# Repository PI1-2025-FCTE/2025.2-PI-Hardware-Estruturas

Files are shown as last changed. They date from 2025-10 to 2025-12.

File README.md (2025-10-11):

# Veículo Autônomo para Depósito de Objetos
Este projeto está vinculado a disciplina de Projeto Integrador 1, da Universidade de Brasília, ministrada pelo Prof. Dr. Lui Txai Calvoso Habl. Tem por objetivo o desenvolvimento de um **veículo autônomo** capaz de seguir trajetórias predefinidas e depositar um objeto do tamanho, proporção e fragilidade de um ovo médio em uma caixa acolchoada ao término da trajetória, sendo operado por uma interface gráfica que retornará o tempo e a trajetória do veiculo. 

[Documentação Latex](https://www.overleaf.com/5331879129xcxkbjkxxrrc#4cba63)

[Esquemático do circuito](https://easyeda.com/editor#project_id=84deaf6a43b146378309fcd01e6a131c)
## Objetivos

- **Trajetórias e Navegação**:
  O carrinho deverá seguir **três diferentes trajetórias**:
  1. **Primeira Trajetória**: Indicação visual com fita isolante no piso.
  2. **Segunda Trajetória**: Indicação visual com fita isolante intermitente.
  3. **Terceira Trajetória**: Indicação de percurso baseada apenas em instruções dadas pelos professores (sem marcação visual).
  
- **Depósito do Objeto**: O carrinho deverá **transportar um objeto frágil (ovo médio)** e entregá-lo de forma segura em uma caixa acolchoada no final da trajetória.

## Etapas do Projeto

### 1. **Desenvolvimento Conceitual**
- Características gerais do carrinho e suas funcionalidades.
- Descrição detalhada do hardware e software envolvidos.
- Análise do consumo energético.

### 2. **Levantamento de Requisitos**
- Brainstorming
- Organização de Requisitos 
- Separação de requisitos por área de desenvolvimento
- Levantamento de Requisitos de baixo nível 

### 3. **Planejamento**
- Definição do cronograma de desenvolvimento.
- Estimativas de custos e orçamento.

### 4. **Prototipagem e Testes**
- Protótipos de hardware e simulação das trajetórias.
- Testes de desempenho (tempo e distância).
- Ajustes e validação de cada parte do sistema.

### 5. **Documentação**
- Desenvolvimento contínuo de artigo científico, documentando cada etapa do projeto.

### 6. **Entrega Final**
- Apresentação do projeto final, incluindo um vídeo de demonstração do funcionamento do carrinho.
- Relatório final com descrição detalhada dos resultados experimentais e análise do desempenho do carrinho.

---

## Tecnologias Utilizadas

- **Hardware**:
  - Sensores de movimento (IMU, giroscópio, etc.).
  - Atuadores (motores, rodas).
  - Microcontroladores e componentes eletrônicos.

- **Software**:
  - Interface gráfica para programação das trajetórias.
  - Banco de dados para registro e análise dos dados coletados.
  - Linguagens de programação: C++, Python, ou outras adequadas para controle de hardware.

- **Comunicação**:
  - Comunicação sem fio (Wi-Fi, Bluetooth, etc.).

## Contribuições

O desenvolvimento do projeto será realizado por uma equipe multidisciplinar, com a contribuição de **engenharias da FCTE** (Faculdade de Ciências e Tecnologia da Engenharia).

Cada membro da equipe será responsável por diferentes áreas, incluindo hardware, software, estrutura, e documentação do projeto.

## Licença

Este projeto está licenciado sob a [Licença MIT](https://opensource.org/licenses/MIT).

---

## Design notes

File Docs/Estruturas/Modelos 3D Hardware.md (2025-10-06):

# Em vez de modelar os componentes eletrônicos perfeitamente, modelar apenas como formas geométricas simplificadas.
## As dimensões estão na planilha: https://unbbr-my.sharepoint.com/:x:/g/personal/221007822_aluno_unb_br/EUa8brnz7TBNpTx4DXP05wEBW7xej8ZXPvB6gErNKME9qA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

- ESP:
https://grabcad.com/library?page=1&time=all_time&sort=recent&query=esp32%20wroom%2032
  - <s> Testado: https://grabcad.com/library/esp32-terminal-adapter-1
  - Compatível: Tem que separar a ESP da placa de dev na modelagem 3d, vem em stl ent tem muitos triângulos, talvez seja melhor procurar outro
  - Dimensões: </s>
  - [x] Modelado
  
- MOTOR:
https://grabcad.com/library/3-6v-dc-gearbox-electromotor-1
  - <s> Testado:
  - Compatível: Precisa converter de .ipt para .stl, provavelmente usando AutoDesk
  - Dimensões: </s>
  - [x] Modelado

- SENSOR VELOCIDADE: 
https://grabcad.com/library/lm393-motor-speed-measuring-sensor-module-1
  - <s> Testado: https://grabcad.com/library/lm393-motor-speed-measuring-sensor-module-1
  - Compatível:
  - Dimensões: 31,3mm X 14,2mm X 11,815mm </s>
  - [x] Modelado

- DISCO ENCODER: 
https://grabcad.com/library/encoder-disk-2
  - <s> Testado: https://grabcad.com/library/encoder-disk-2 
  - Compatível: Arquivo "encoder disk.STEP"
  - Dimensões: D: 25,756 mm / Espessura máx: 3,175 mm / Espessura mín: 2,54 mm </s>
  - [x] Modelado

- RODA TRASEIRA:
  - <s> Testado:
  - Compatível:
  - Dimensões: </s>
  - [x] Modelado

- ACELERÔMETRO: 
https://grabcad.com/library/mpu-9250-1
  - <s> Testado: https://grabcad.com/library/mpu-9250-1
  - Compatível: Arquivo "MPU-9250.stp"
  - Dimensões: 15 mm x 25 mm x 12,696 mm (Profundidade máxima devido ao tamanho dos pinos presentes no CAD) </s>
  - [x] Modelado
    
- RODA DIANTEIRA: 
https://grabcad.com/library?page=1&time=all_time&sort=recent&query=ball%20caster
  - <s> Testado:
  - Compatível:
  - Dimensões: </s>
  - [ ] Modelado
    
- PLACA DE DESENVOLVIMENTO:
https://grabcad.com/library/esp32-deek-robot-terminal-adapter-1
  - <s> Testado: https://grabcad.com/library/esp32-terminal-adapter-1
  - Compatível: Talvez tenha que remodelar para corresponder ao modelo comprado (e separar da ESP)
  - Dimensões: </s>
  - [x] Modelado
    
- SENSOR DE ULTRASSONICO Hc-sr04:
  - [x] Modelado

- PONTE H L298N:
  - [x] Modelado

- BATERIA NiMH 6 V (2000 mAh):
  - [x] Modelado

- CÉLULA 18650 3,7 V (2200 mAh):
  - [ ] Modelado

- REGULADOR DE TENSÃO LM2596:
  - [x] Modelado

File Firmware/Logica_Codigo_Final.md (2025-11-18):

## Dados de Sensores
As tasks são chamadas a cada *x* ms (esse valor é definido no próprio código).

- Arquivo: `Firmware/BasicOTAplusMultitaskplusODP_PI1/BasicOTAplusMultitaskplusODP_PI1.ino`

### Encoder
- Usa interrupção de pino.
- Toda vez que a interrupção é chamada, incrementa-se a distância percorrida.

---

## Decodificação
A cada novo conjunto de instruções recebido (quando a função callback é chamada), as instruções são decodificadas enquanto são executadas.

- Arquivo: `decodificaInstrucoes.ino`

---

## Controle dos Motores
É necessário escrever um código que utilize PWM nos motores para garantir transições suaves ao executar as instruções.  
Toda essa parte será implementada por meio de métodos da biblioteca `AGV_Eric.h`.

---

# Formato Básico do Código Completo

```cpp
// Importação de bibliotecas
// Definição de funções (puxar dados dos sensores, comunicação Wi-Fi…)

void setup() {
    // Inicialização de comunicações
    // Inicialização do Wi-Fi
    // Inicialização das interrupções do encoder
    // (attachInterrupt(digitalPinToInterrupt(ENCODER_PIN), encoderISR, RISING);)
    
    // Definição das tasks
}

void loop() {
    // Nada aqui
}

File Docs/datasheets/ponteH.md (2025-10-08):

# Ponte H com motores DC

Este circuito é composto por diversos componentes que permitem o controle de dois motores DC usando uma ponte H L298N, juntamente com reguladores de tensão L7805 e LM317, e um microcontrolador ESP32 WROOM. A seguir, detalharemos a função e a ligação de cada componente:

## Componentes

1. **Ponte H L298N (Driver de Motor)**
   - A L298N é uma ponte H que permite controlar dois motores DC (DC Motor 1 e DC Motor 2).
   - Ela possui 4 entradas lógicas (IN1, IN2, IN3, IN4) que controlam o sentido de rotação dos motores e as saídas (OUT1, OUT2, OUT3, OUT4) conectadas aos motores.
   
2. **Motores DC**
   - São dois motores DC (Motores 1 e 2), controlados pela ponte H L298N.
   
3. **Controlador de Tensão L7805 (Regulador de 5V)**
   - O L7805 é um regulador de tensão linear que converte a tensão de entrada (VCC) para 5V, que é fornecida à L298N para alimentação de suas entradas lógicas.
   
4. **Controlador de Tensão LM317 (Regulador de 3.3V)**
   - O LM317 é um regulador de tensão ajustável, neste caso configurado para fornecer 3.3V, que é a alimentação da ESP32.
   
5. **Microcontrolador ESP32 WROOM**
   - O ESP32 é o cérebro do sistema, controlando a ponte H e os motores através das portas lógicas. Ele recebe alimentação de 3.3V via o LM317 e usa as portas digitais para controlar a direção dos motores.

## Esquemático de Conexões

``` 
                            +-------------------------+
                            |                         |
                          +-+---+       +---------+   |  
VCC --------------------| L298N |-----> | Motores  |   |
                          +-----+       +---------+   |
                               |                     |
       IN1 (GPIO 17) ----------+                     |
       IN2 (GPIO 16) ----------+                     |
       IN3 (GPIO 33) ----------+                     |
       IN4 (GPIO 32) ----------+                     |
                               |                     |
      5V -----------------> L7805 -----> 5V para IN1/2/3/4
      3.3V -----------------> LM317 -----> 3.3V para ESP32
      GND -------------------> GND de todos os dispositivos
````

## Funcionamento do Circuito

1. Controle dos Motores DC

O microcontrolador ESP32 controla os motores através da ponte H L298N. As portas digitais (GPIO 17 e 16 para os primeiros dois pinos IN) e (GPIO 33 e 32 para os dois últimos pinos IN) são usadas para determinar a direção dos motores conectados às saídas (OUT1, OUT2 para o motor 1 e OUT3, OUT4 para o motor 2).

2. Regulação de Tensão

O regulador de tensão L7805 converte a alimentação VCC do sistema para 5V, que é necessária para alimentar as entradas lógicas da ponte H L298N.

O regulador LM317 é configurado para fornecer uma tensão de 3.3V, que alimenta o ESP32, garantindo que ele opere na tensão correta.

3. Conexões de GND

Todos os dispositivos compartilham o mesmo GND, garantindo que o circuito tenha uma referência de aterramento comum, essencial para o correto funcionamento da lógica de controle.

## Diagrama Esquemático

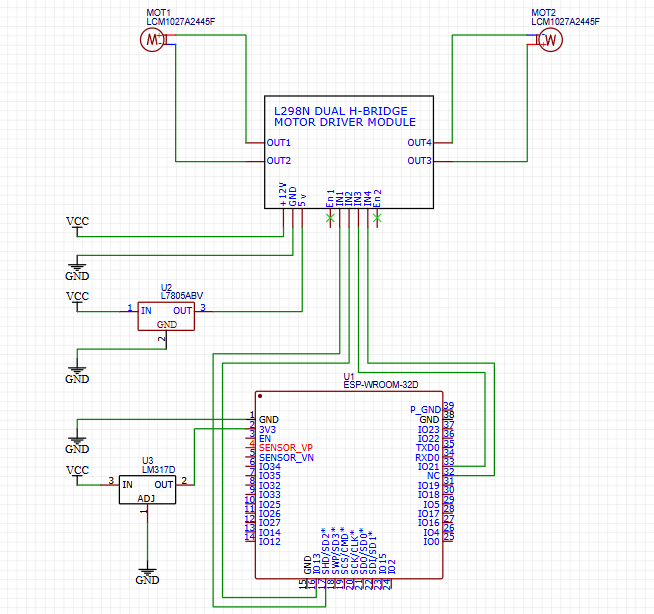
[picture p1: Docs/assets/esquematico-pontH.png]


Este diagrama do circuito mostra todas as conexões entre os componentes. Como descrito acima, as entradas da ponte H são controladas pelas portas lógicas do ESP32, enquanto os motores DC são alimentados e controlados por ela. O regulador de tensão L7805 garante que a Ponte H receba 5V para sua entrada lógica, e o regulador de tensão LM317 fornece os 3.3V necessários para o ESP32.

ass. @EricAraujoBsB

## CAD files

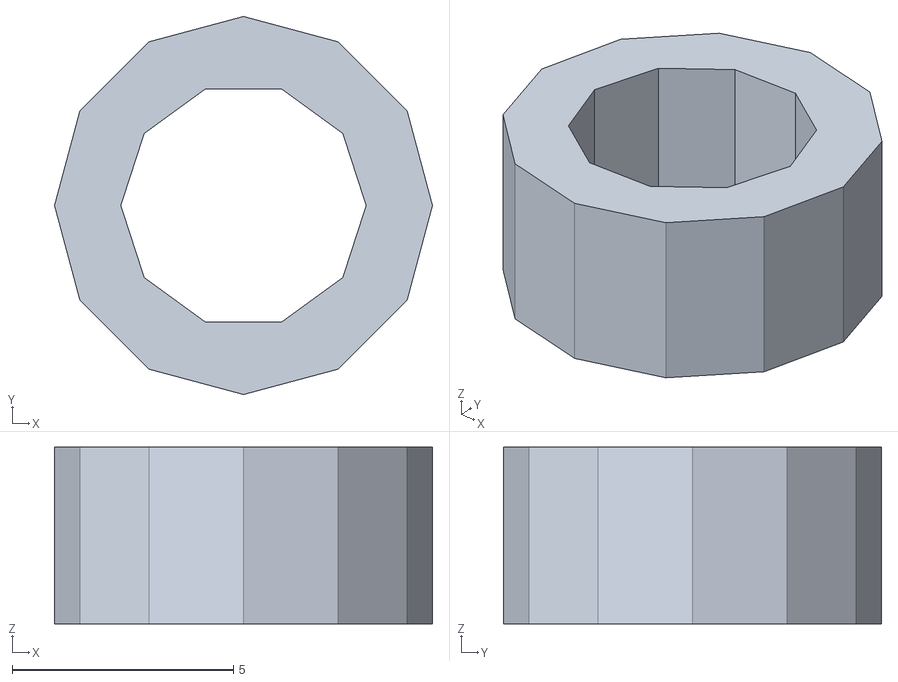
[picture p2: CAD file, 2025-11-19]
Docs/Estruturas/Modelos3D/espacador.stl
8.55 x 8.55 x 4.00

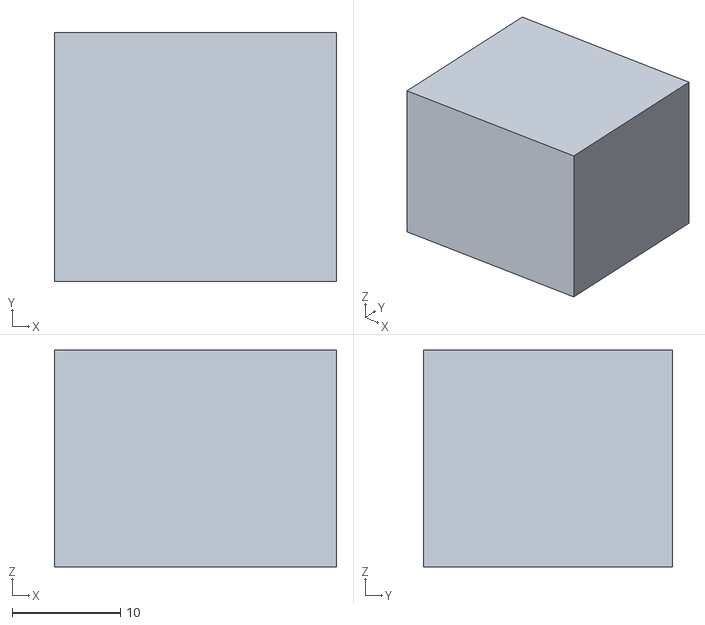
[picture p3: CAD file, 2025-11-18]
Docs/Estruturas/Modelos3D/Apoio_Sensor_Corrente.stl
26.0 x 23.0 x 20.0

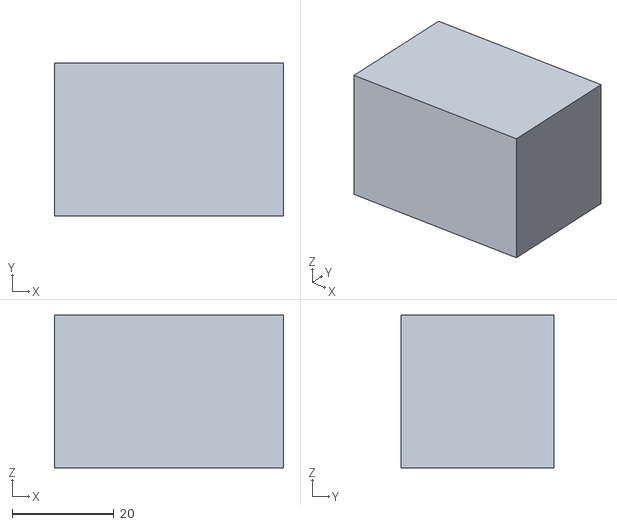
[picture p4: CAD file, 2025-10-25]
Docs/Estruturas/Modelos3D/Formas Simplificadas/apoio.stl
45.0 x 30.0 x 30.0

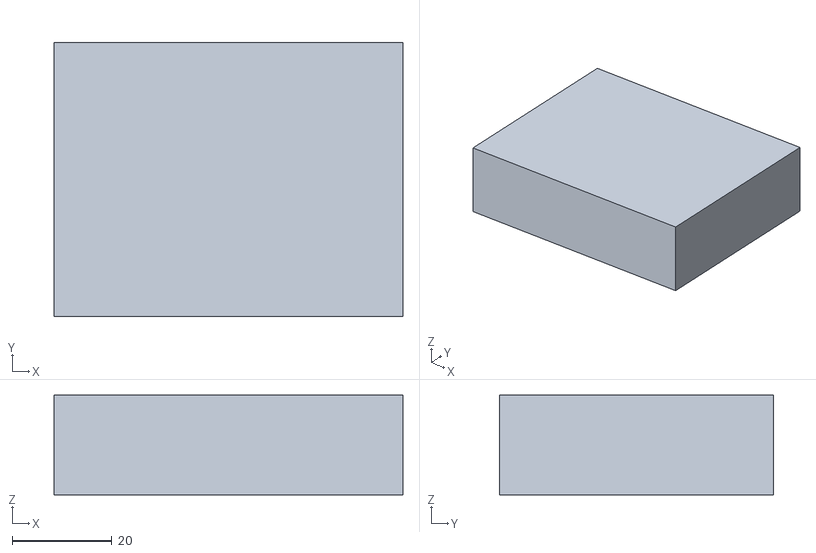
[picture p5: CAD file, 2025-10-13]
Docs/Estruturas/Modelos3D/Formas Simplificadas/PlacaDesenvolvimentoParalelepipedo.stl
70.0 x 55.0 x 20.0

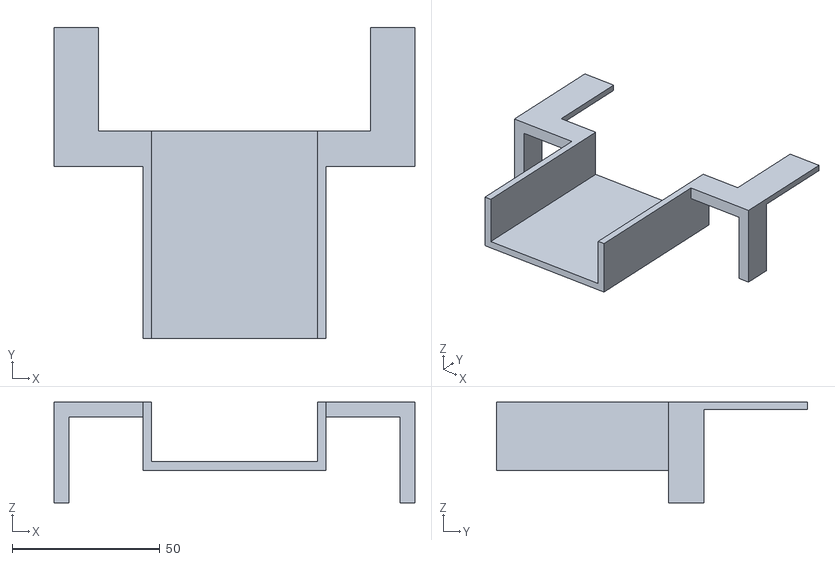
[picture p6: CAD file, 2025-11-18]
Docs/Estruturas/Modelos3D/Suporte_motor_Pro_Max.stl
122.0 x 105.0 x 34.0

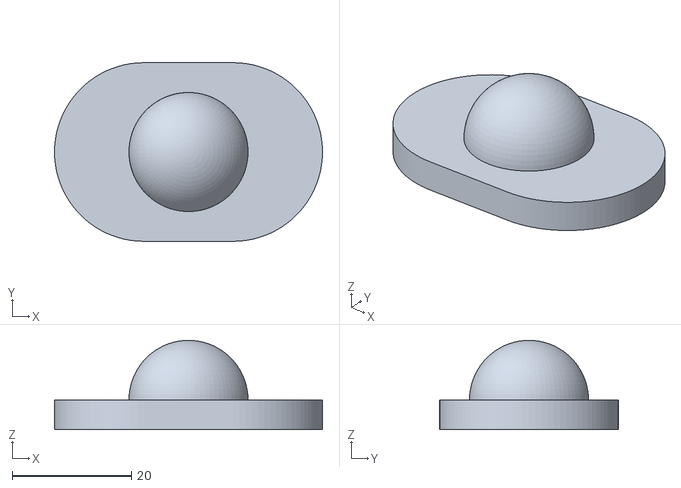
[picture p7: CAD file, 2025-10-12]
Docs/Estruturas/Modelos3D/Formas Simplificadas/RodaRolete.stl
45.0 x 30.0 x 15.0

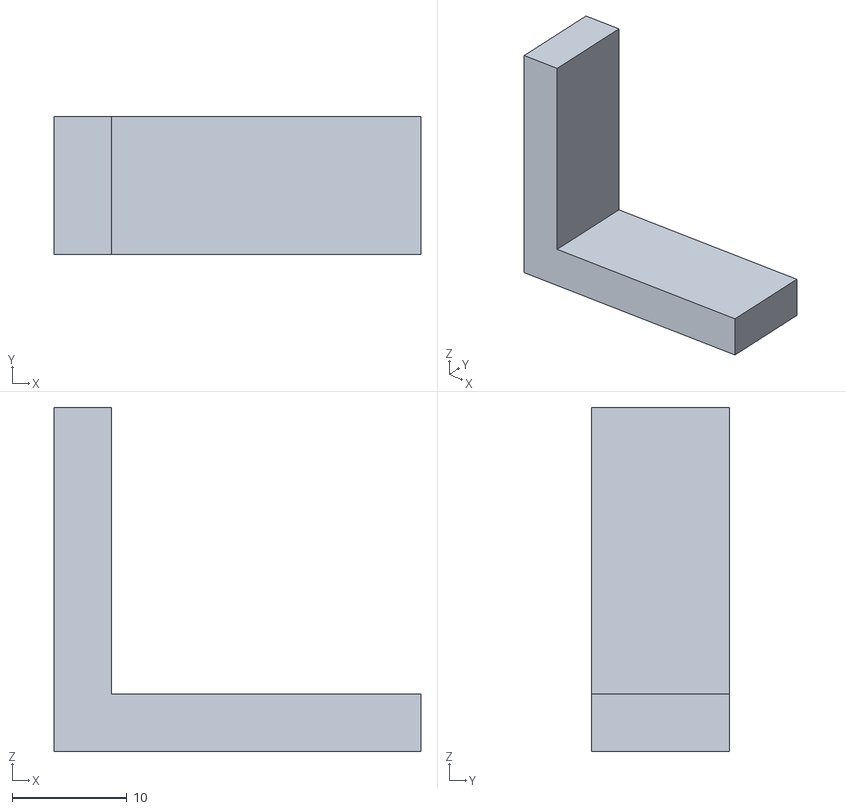
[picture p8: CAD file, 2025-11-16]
Docs/Estruturas/Modelos3D/SuporteMotorNovo.stl
32.0 x 12.0 x 30.0

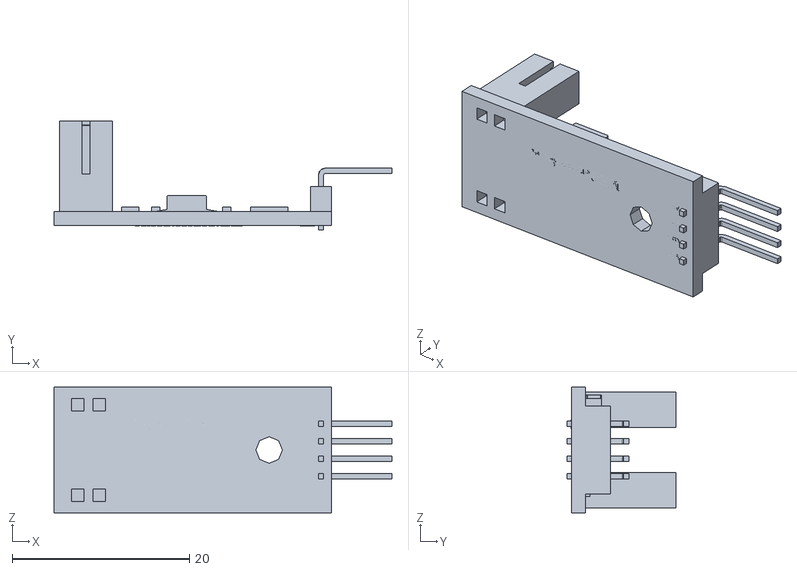
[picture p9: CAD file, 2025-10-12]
Docs/Estruturas/Modelos3D/Formas Simplificadas/Lm393speed.stl
38.1 x 12.3 x 14.2

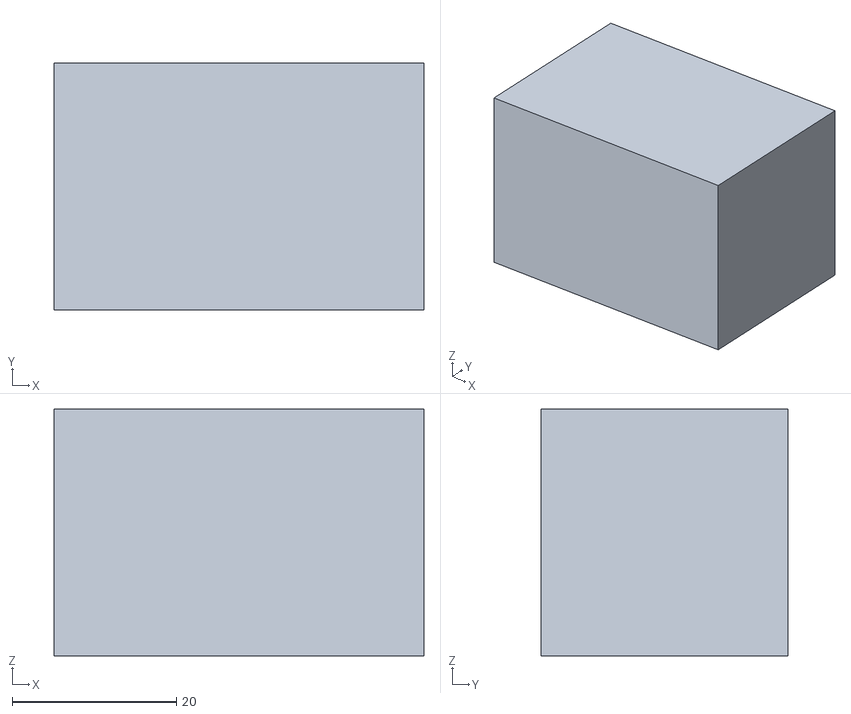
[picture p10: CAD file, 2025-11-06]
Docs/Estruturas/Modelos3D/SuporteRolete.stl
45.0 x 30.0 x 30.0

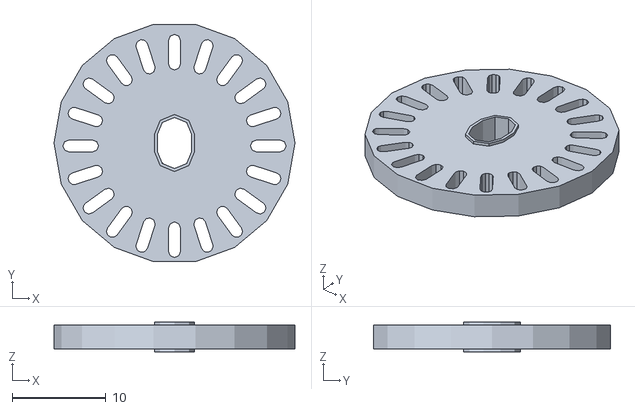
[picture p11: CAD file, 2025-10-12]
Docs/Estruturas/Modelos3D/Formas Simplificadas/encoderdisk.stl
25.8 x 25.4 x 3.17

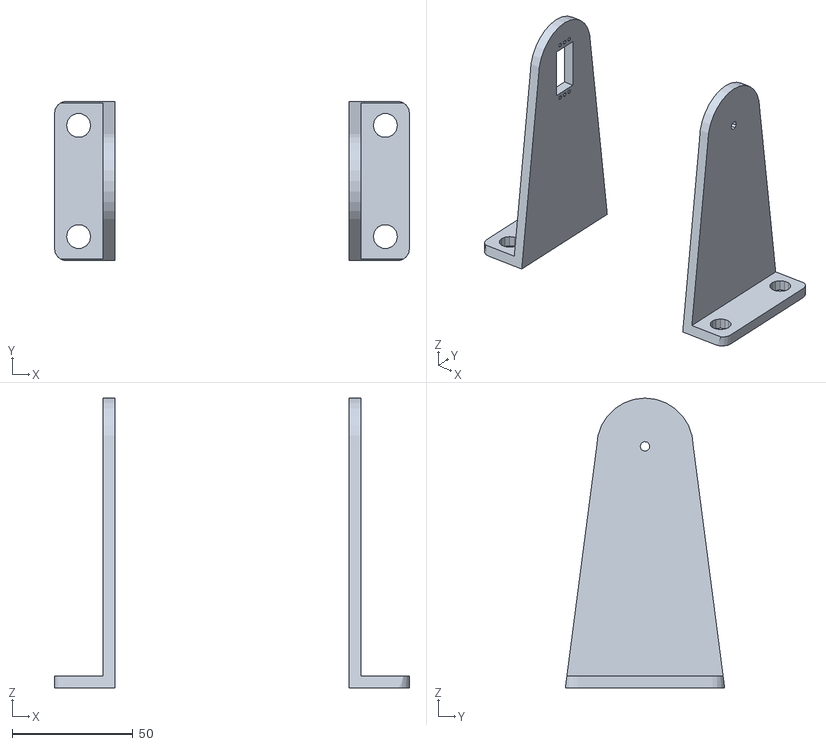
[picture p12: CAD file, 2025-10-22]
Docs/Estruturas/Modelos3D/Pringles Can Support.stl
147.0 x 66.0 x 120.0

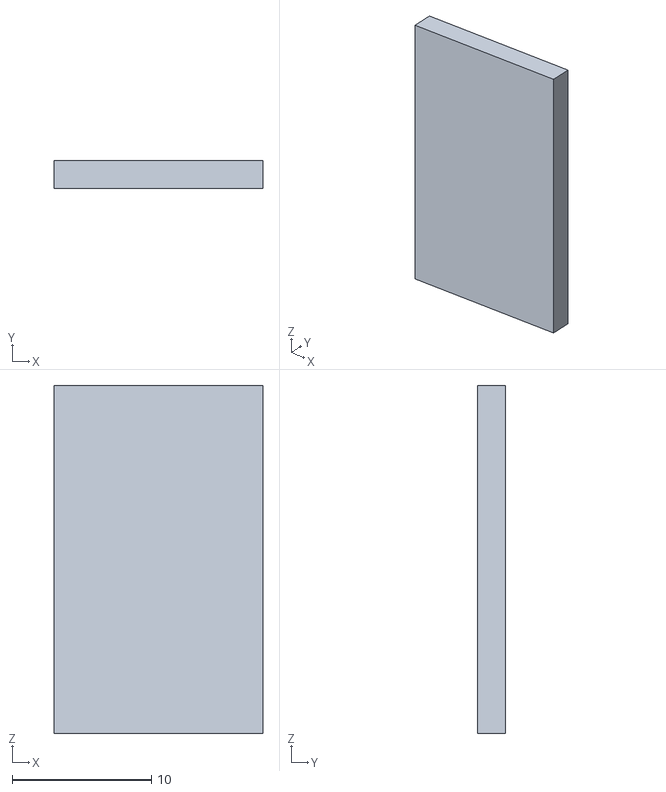
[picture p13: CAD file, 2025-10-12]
Docs/Estruturas/Modelos3D/Formas Simplificadas/AcelerometroParalelepipedo.stl
15.0 x 2.00 x 25.0

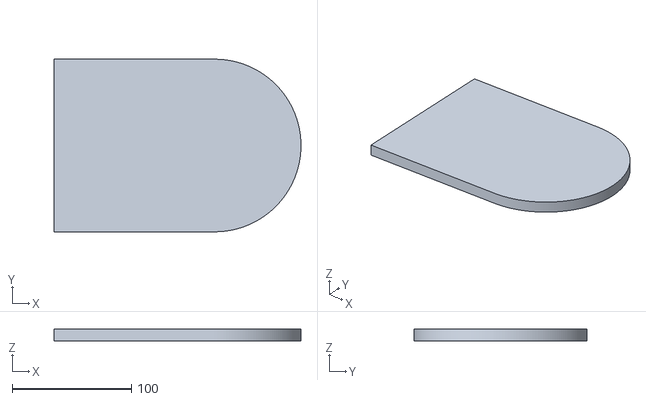
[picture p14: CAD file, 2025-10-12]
Docs/Estruturas/Modelos3D/Formas Simplificadas/Chassi_Def.stl
207.5 x 145.0 x 10.0

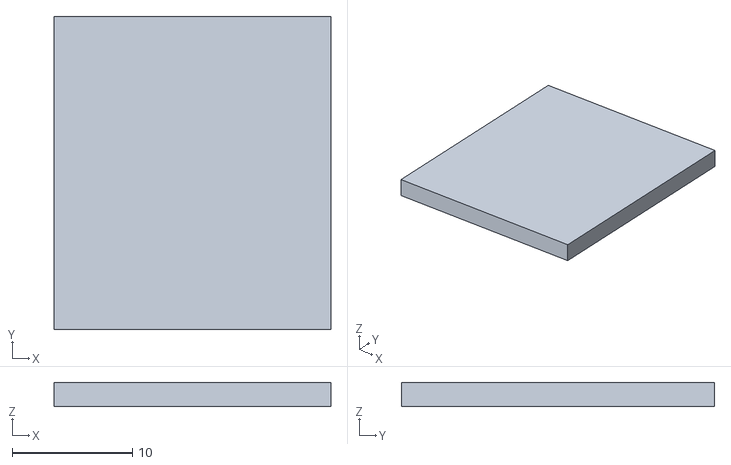
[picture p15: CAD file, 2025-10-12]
Docs/Estruturas/Modelos3D/Formas Simplificadas/SensordeCorrenteINA219.stl
23.0 x 26.0 x 2.00

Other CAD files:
Docs/Estruturas/Modelos3D/Formas Simplificadas/PlacaIlhada.stl
Docs/Estruturas/Modelos3D/Formas Simplificadas/ReguladorLM2596.stl
Docs/Estruturas/Modelos3D/Formas Simplificadas/proximidade.stl
Docs/Estruturas/Modelos3D/Chassi_Def.CATPart
Docs/Estruturas/Modelos3D/Gear_2.CATPart
Docs/Estruturas/Modelos3D/Placa_Desenvolvimento.CATPart
Docs/Estruturas/Modelos3D/RodaRolete.CATPart
Docs/Estruturas/Modelos3D/Suporte_motor_Pro_Max.CATPart

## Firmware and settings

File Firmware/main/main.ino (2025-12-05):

#include <Wire.h>
#include <Adafruit_INA219.h>
#include <Adafruit_MPU6050.h>
#include <Adafruit_Sensor.h>
#include <WiFi.h>
#include <PubSubClient.h>
#include <ArduinoJson.h>
#include <ArduinoOTA.h>
#include "WiFiUdp.h"
// #include "HCSR04.h"
// #include "../bateria/bateria.h"
#include "Atuadores.h"
#include "Encoder.h"
#include <ESP32Servo.h>

// === Bluetooth ===
// #include "BluetoothSerial.h"
// String device_name = "ESP32-BT-Logger";
// BluetoothSerial SerialBT;

// Check if Bluetooth is available
// #if !defined(CONFIG_BT_ENABLED) || !defined(CONFIG_BLUEDROID_ENABLED)
// #error Bluetooth is not enabled! Please run `make menuconfig` to and enable it
// #endif

// // Check Serial Port Profile
// #if !defined(CONFIG_BT_SPP_ENABLED)
// #error Serial Port Profile for Bluetooth is not available or not enabled. It is only available for the ESP32 chip.
// #endif

// === Definição dos pinos I2C ===
#define SDA_1 19
#define SCL_1 18
#define SDA_2 21
#define SCL_2 22

// === Armazenamento dos comandos ===
typedef struct Trajeto {
  String comandosEnviados;    // única string, texto longo
  String comandosExecutados;  // idem
  int status;
  long tempo;
  int ID;
} Trajeto;

Trajeto t;

int distanciaUltrassom;
bool trajetoComprometido = false;
bool condicaoDeParada = false;
bool trajetoInterceptado = false;
bool umComandoFoiRecebido = false;
bool trajetoPodeSerPublicado = false;
// === Wifi ===
// Configurações WiFi
const char* ssid = "ANDRE_5907";
const char* password = "99634M{m";

// === Comunicacao MQTT ===
// Configurações MQTT
const char* mqtt_server = "192.168.137.1";  // Exemplo: "broker.hivemq.com"
const int mqtt_port = 1883;
const char* mqtt_user = "user";      // seu usuário MQTT
const char* mqtt_pass = "password";  // sua senha MQTT
const char* data_topic = "esp32.data";
const char* device_id = "esp32";
const char* status_topic = "devices/esp32/status";
const char* trajeto_topic = "devices/esp32/trajeto";
const char* client_topic = "devices/esp32/commands";
// Instancia WiFi e MQTT
WiFiClient espClient;
PubSubClient client(espClient);

// === Comunicacao UDP ===
WiFiUDP udp;
const char* udp_host = "192.168.0.10";  // IP do PC/servidor que vai receber
const uint16_t udp_port = 5005;         // porta em que o PC escuta (ex.: 5005)

// === Giroscópio ===
// float yaw = 0.0;
// float gyroBiasZ = 0.0;
// unsigned long lastTime = 0;
// // Filtro low-pass para gz
// static float gz_filt = 0;
// const float alpha = 0.98;  // Filtro: 98% anterior + 2% novo

// Calibração do giroscópio
// void calibrarGyroZ();

// Atualiza o yaw
// float atualizarYaw();

// Gira até atingir o ângulo especificado
void girarAte(float anguloAlvo);

// === Criação das interfaces I2C ===
TwoWire I2C_1 = TwoWire(0);
TwoWire I2C_2 = TwoWire(1);

// === Criação dos sensores ===
Adafruit_INA219 ina219(0x40);
float porcentagem;
#define TENSAO_MAXIMA 7.24
#define TENSAO_MINIMA 5.5

Adafruit_MPU6050 mpu6050;
// unsigned long lastStatusTime = 0;
// Instância dos motores e do AGV
// DCMotor Motor1, Motor2;
AGV AGV1;
Encoder encoderEsq(0);
Encoder encoderDir(1);
// HCSR04 sensorUltrassonico;
#define trigPin 17
#define echoPin 5
Servo servo_1;
uint8_t motor_angle;

void setup() {
  Serial.begin(115200);
  delay(3000);

  pinMode(trigPin, OUTPUT);
  pinMode(echoPin, INPUT);
  
  // Ensure trigger pin is low
  digitalWrite(trigPin, LOW);
  delayMicroseconds(2);

  // sensorUltrassonico.PinOut(17, 5);
  setup_wifi();
  client.setServer(mqtt_server, mqtt_port);
  client.setCallback(callback);
  reconnect();
  ArduinoOTA.begin();

  servo_1.attach(15);
  AGV1.Create(25, 26, 33, 32, 220);  // Inicializando o AGV com os pinos dos motores
  encoderEsq.PinOut(27, 0);          // Exemplo
  encoderDir.PinOut(4, 1);           // Exemplo

  // Inicializando I2C_1 para o INA219
  I2C_1.begin(SDA_1, SCL_1, 100000);
  if (!ina219.begin(&I2C_1)) {  // Endereço padrão do INA219 é 0x40
    Serial.println("Não foi possível encontrar o INA219!");
  } else {
    Serial.println("INA219 detectado no barramento 1.");
  }

  // Inicializando I2C_2 para o MPU6050
  I2C_2.begin(SDA_2, SCL_2, 100000);
  if (!mpu6050.begin(0x68, &I2C_2)) {  // Endereço padrão do MPU6050 é 0x68
    Serial.println("Não foi possível encontrar o MPU6050!");
  } else {
    Serial.println("MPU6050 detectado no barramento 2.");
  }

  Serial.println("Pronto para leituras!\n");
  // lastStatusTime = millis();

  // logQueue = xQueueCreate(20, sizeof(const char*));

  xTaskCreatePinnedToCore(taskColetaDados, "Data", 4096, NULL, 1, NULL, 1);
  // xTaskCreatePinnedToCore(taskExec, "Exec", 4096, NULL, 1, NULL, 1);
  xTaskCreatePinnedToCore(taskOTA, "OTA", 4096, NULL, 1, NULL, 0);
  xTaskCreatePinnedToCore(taskWifi, "TMQTT", 4096, NULL, 1, NULL, 0);
  // xTaskCreatePinnedToCore(taskBlink, "Blink", 2048, NULL, 1, NULL, 1);

  servo_1.write(180);  // Posição inicial do servo
}

void loop() {

  // SerialBT.println("===== Monitor de Bateria =====");
  // Teste();
  if (umComandoFoiRecebido) {
    long tempoTrajetoInicio = millis();
    decodificaExecutaInstrucao(t.comandosEnviados);
    if (!trajetoInterceptado){
      if (distanciaUltrassom < 4){
        entregaCarga();
      } else {
          trajetoComprometido = true;
      }
    } else {
        trajetoInterceptado = false;
    }
    t.tempo = millis() - tempoTrajetoInicio;
    trajetoPodeSerPublicado = true;
    umComandoFoiRecebido = false;
  }
}

// === Enfileira mensagens de log ===
// void logMessage(const char* msg) {
//   if (logQueue != NULL) {
//     xQueueSend(logQueue, &msg, 0);
//   }
// }

void taskColetaDados(void* pvParameters) {
  for (;;) {
    monitorarBateria();
    distanciaUltrassom = calculaDistancia();
    Serial.printf("Distancia do sensor HSRC = %d cm\n", distanciaUltrassom);
    publicarStatus();
    vTaskDelay(pdMS_TO_TICKS(500));
  }
}

void taskWifi(void* pvParameters) {
  for (;;) {
    if (!client.connected()) {
      reconnect();
    }
    client.loop();
    if(trajetoPodeSerPublicado){
      publicarTrajeto(t);
      trajetoPodeSerPublicado = false;
    }
    vTaskDelay(pdMS_TO_TICKS(100));
  }
}

// === Task OTA (Core 0) ===
void taskOTA(void* pvParameters) {
  for (;;) {
    ArduinoOTA.handle();
    vTaskDelay(pdMS_TO_TICKS(50));
  }
}

void entregaCarga(){
  servo_1.write(180);
  for(uint8_t i = 180; i>=140; i--){
    servo_1.write(i);
    delay(15);
  }
  delay(3000);
  servo_1.write(180);
}

int distanciaPorCm(float cm) {
  // float distancia = encoderEsq.calcularDistancia();
  // float distanciaEnc2 = encoderDir.calcularDistancia();
  // float distancia = (distanciaEnc1 + distanciaEnc2) / 2.0;
  float dist = 0;
  encoderDir.deletaDistancia();
  encoderEsq.deletaDistancia();
  AGV1.ForwardAGV();
  while (dist < cm) {
    if(condicaoDeParada) {
      break;
    }
    dist = encoderDir.calcularDistancia();
    // Serial.printf("Distancia = %f\n", dist);
    // UdpLogf("Distancia = %f\n", dist);
    // SerialBT.printf("Distancia = %f\n", dist);
    // delay(100);
  }
  AGV1.StopAGV();
  encoderDir.deletaDistancia();
  encoderEsq.deletaDistancia();
  delay(1000);
  return dist;
}

void Gira90GrausDireita() {
  float dist = 0;
  encoderDir.deletaDistancia();
  encoderEsq.deletaDistancia();
  AGV1.RightAGV();           // Diametro entre rodas = 19.45 cm
  while (dist < 14) {  // 19.45 * 3.14 * (90.0 / 360.0) calcula o comprimento do arco para 90 graus
    if(condicaoDeParada) {
      break;
    }
    dist = encoderDir.calcularDistancia();
    // Serial.printf("Distancia = %f\n", dist);
    // UdpLogf("Distancia = %f\n", dist);
    // SerialBT.printf("Distancia = %f\n", dist);
    // delay(100);
  }
  AGV1.StopAGV();
  encoderDir.deletaDistancia();
  encoderEsq.deletaDistancia();
  delay(1000);
  // return dist;
}

void Gira90GrausEsquerda() {
  float dist = 0;
  encoderDir.deletaDistancia();
  encoderEsq.deletaDistancia();
  AGV1.LeftAGV();
  while (dist < 15) {  // 19.45 * 3.14 * (90.0 / 360.0) calcula o comprimento do arco para 90 graus (teste com 13.40082312)
    if(condicaoDeParada) {
      break;
    }
    dist = encoderDir.calcularDistancia();
    // Serial.printf("Distancia = %d\n", dist);
    // UdpLogf("Distancia = %f\n", dist);
    // SerialBT.printf("Distancia = %f\n", dist);
    // delay(100);
  }
  AGV1.StopAGV();
  AGV1.StopAGV();
  encoderDir.deletaDistancia();
  encoderEsq.deletaDistancia();
  delay(1000);
  // return dist;
}

void decodificaExecutaInstrucao(String buffer) {
  int i = 0;
  Serial.printf("Buffer: %s\n", buffer.c_str());  // .c_str() converte String para const char*
  while (i < buffer.length()) {                   // .length() ao invés de strlen()
    if(condicaoDeParada) {
      condicaoDeParada = false;
      trajetoInterceptado = true;
      break;
    }
    if (buffer[i] == 'a') {
      // char comprimento[5] = "";
      i++;  // Avança para o primeiro dígito após o 'a'

      // Pega EXATAMENTE 4 dígitos OU até fim
      int fim = min(i + 4, (int)buffer.length());
      String numeroStr = buffer.substring(i, fim);

      int valor = numeroStr.toInt();  // Converte String → int
      Serial.printf("Avancando %d cm\n", valor);
      int dist = distanciaPorCm((float)valor) * 100;
      String cmd = "a";

      // distância sempre com 4 dígitos (zero à esquerda)
      if (dist < 0) dist = 0;
      if (dist > 999999) dist = 999999;

      if (dist < 1000) cmd += "000";
      else if (dist < 10000) cmd += "00";
      else if (dist < 100000) cmd += "0";
      cmd += String(dist);  // agora vira "0100"
      t.comandosExecutados += cmd;
      // SerialBT.printf("Comando executado: %s", t.comandosExecutados);
      // logMessage("Comando executado: %s", t.comandosExecutados);
      Serial.printf("Comando executado: %s", t.comandosExecutados.c_str());
      UdpLogf("Comando executado: %s", t.comandosExecutados.c_str());
      i = fim;  // Pula os 4 dígitos
    } else if (buffer[i] == 'd') {
      Serial.printf("Virando à direita\n");
      Gira90GrausDireita();
      i++;
      t.comandosExecutados += 'd';
      // SerialBT.printf("Comando executado: %s", t.comandosExecutados);
      Serial.printf("Comando executado: %s\n", t.comandosExecutados.c_str());
      UdpLogf("Comando executado: %s", t.comandosExecutados.c_str());
    } else if (buffer[i] == 'e') {
      Serial.printf("Virando à esquerda\n");
      Gira90GrausEsquerda();
      i++;
      t.comandosExecutados += 'e';
      // SerialBT.printf("Comando executado: %s", t.comandosExecutados);
      Serial.printf("Comando executado: %s\n", t.comandosExecutados.c_str());
      UdpLogf("Comando executado: %s", t.comandosExecutados.c_str());
    } else if (buffer[i] == 'i') {
      i++;
      int fim = min(i + 2, (int)buffer.length());
      String numeroStr = buffer.substring(i, fim);
      t.ID = numeroStr.toInt();
      ;
      Serial.printf("ID do trajeto: %d\n", t.ID);
      UdpLogf("ID do trajeto: %d", t.ID);
    } else {
      i++;  // Pula caracteres desconhecidos
    }
  }
}


void Teste() {
  if (Serial.available()) {
    String leitura = Serial.readStringUntil('\n');
    leitura.trim();  // Remove \r\n e espaços
    Serial.printf("Comando recebido: [%s]", leitura);
    // SerialBT.printf("Comando recebido: [%s]", leitura);
    if (leitura == "andar1") {
      distanciaPorCm(50.0);  // Move o AGV para frente por 50 cm
      // AGV1.ForwardAGV();
      // Serial.println("AGV Andando pra frente");
      // delay(5000);
      // AGV1.StopAGV();
      // Serial.println("AGV Parado");
    } else if (leitura == "andar2") {
      distanciaPorCm(100.0);
    } else if (leitura == "del") {
      encoderDir.deletaDistancia();
      encoderEsq.deletaDistancia();
    } else if (leitura == "andar3") {
      // Serial.println("AGV andando pra frente");
      // AGV1.ForwardAGV();
      distanciaPorCm(200.0);
    } else if (leitura == "andar4") {
      // Serial.println("AGV andando pra tras");
      // AGV1.BackwardAGV();
      distanciaPorCm(500.0);
    } else if (leitura == "parar") {
      // Serial.println("AGV parado");
      AGV1.StopAGV();
    } else if (leitura == "right") {
      Serial.println("Girando 90 graus para a direita");
      Gira90GrausDireita();
    } else if (leitura == "left") {
      Serial.println("Girando 90 graus para a esquerda");
      Gira90GrausEsquerda();
    } else {
      decodificaExecutaInstrucao(leitura);
    }
  }
}

// === Funcoes do Wifi e MQTT
// Publica o status
void publicarStatus() {
  StaticJsonDocument<128> doc;
  doc["online"] = true;  //alterar isto
  doc["battery"] = porcentagem;   //alterar isto
  char buffer[128];
  size_t n = serializeJson(doc, buffer);
  client.publish(status_topic, buffer, n);
  // Serial.println("Status publicado!");
}

// Publica o trajeto
void publicarTrajeto(Trajeto trajeto) {
  StaticJsonDocument<192> doc;
  doc["idTrajeto"] = trajeto.ID;
  doc["Executadas"] = trajeto.comandosExecutados;
  doc["device_id"] = "esp32";
  doc["tempo"] = t.tempo;
  if(trajetoComprometido){
    doc["status"] = false;
  } else {
    doc["status"] = true;
  }
  trajetoComprometido = false;
  char buffer[192];
  size_t n = serializeJson(doc, buffer);
  client.publish(trajeto_topic, buffer, n);
  Serial.println("Trajeto publicado!");
  t.comandosEnviados = "";
  t.comandosExecutados = "";
  t.ID = 0;
  t.tempo = 0;
}

// Função para conectar WiFi
void setup_wifi() {
  delay(10);
  WiFi.begin(ssid, password);
  while (WiFi.status() != WL_CONNECTED) {
    Serial.printf("Nao foi possivel conectar-se ao wifi.\n");
    delay(500);
  }
  Serial.printf("Conectado ao wifi!\n");
  digitalWrite(2, HIGH);
  udp.begin(12345);  // porta local qualquer
}

// Função para conectar MQTT
void reconnect() {
  while (!client.connected()) {
    if (client.connect("ESP32Client", mqtt_user, mqtt_pass)) {
      Serial.printf("Conectado ao cliente!\n");
      client.subscribe(client_topic);
      digitalWrite(2, LOW);
      delay(100);
      digitalWrite(2, HIGH);
      delay(100);
      digitalWrite(2, LOW);
      delay(100);
      digitalWrite(2, HIGH);
    } else {
      // if(Serial.available()){
      //   String mqtt_server = Serial.readStringUntil('\n');
      // }
      delay(5000);
      Serial.println("Tentando conectar-se ao cliente.");
    }
  }
}

//Funcao que recebe mensagens
void callback(char* topic, byte* payload, unsigned int length) {
  // Crie um buffer para armazenar a string do payload
  char buffer[256];
  if (length >= sizeof(buffer)) length = sizeof(buffer) - 1;  // evita overflow
  memcpy(buffer, payload, length);
  buffer[length] = '\0';  // Termina a string corretamente
  Serial.println("Foram recebidos comandos!");
  UdpLogf("Comando recebido via MQTT: %s", buffer);
  // Agora, atribua uma cópia para comandosEnviados
  t.comandosEnviados = String(buffer);  // strdup faz cópia dinâmica
  if(t.comandosEnviados == "STOP"){
    condicaoDeParada = true;
    Serial.println("CARRINHO DEVE PARAR");
  } else {
    Serial.printf("Comando recebido e armazenado: %s\n", t.comandosEnviados);
    umComandoFoiRecebido = true;
  }
}

// Funções para envio de logs via UDP
void UdpLog(const char* msg) {
  udp.beginPacket(udp_host, udp_port);
  udp.write((const uint8_t*)msg, strlen(msg));
  udp.endPacket();
}

void UdpLogf(const char* fmt, ...) {
  char buf[256];
  va_list args;
  va_start(args, fmt);
  vsnprintf(buf, sizeof(buf), fmt, args);
  va_end(args);
  UdpLog(buf);
}

int calculaDistancia(){
    // Send a 10 microsecond high pulse to trigger the sensor
  digitalWrite(trigPin, HIGH);
  delayMicroseconds(10);
  digitalWrite(trigPin, LOW);

  // Read the echo pin, which returns the duration of the pulse in microseconds
  long duration = pulseIn(echoPin, HIGH);

  // Calculate distance in centimetres
  int distance = duration * 0.034 / 2;
  return distance;
}

void monitorarBateria() {
    // Leitura direta do sensor INA219
  float voltagemBateria = ina219.getBusVoltage_V();
  float correnteAmperes = ina219.getCurrent_mA() / 1000.0; // Converte mA para A
  float potenciaWatts = ina219.getPower_mW() / 1000.0; // Converte mW para W
  porcentagem = calcularPorcentagem(voltagemBateria);

  Serial.print("Tensão: ");
  Serial.print(voltagemBateria, 2);
  Serial.print(" V | Corrente: ");
  Serial.print(correnteAmperes, 3);
  Serial.print(" A | Potência: ");
  Serial.print(potenciaWatts, 3);
  Serial.print(" W | Bateria: ");
  Serial.print(porcentagem);
  Serial.println(" %");
  
  // Aviso de bateria baixa
  if (porcentagem <= 20) {
    Serial.println("AVISO: Bateria baixa!");
  }
}

int calcularPorcentagem(float tensao) {
  if (tensao >= TENSAO_MAXIMA) return 100;
  if (tensao <= TENSAO_MINIMA) return 0;

  return (int)((tensao - TENSAO_MINIMA) / (TENSAO_MAXIMA - TENSAO_MINIMA) * 100.0);
}

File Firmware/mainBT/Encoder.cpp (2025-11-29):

#include "Encoder.h"

Encoder* Encoder::instanciaEncoder1 = nullptr;
Encoder* Encoder::instanciaEncoder2 = nullptr;

Encoder::Encoder(int interruptNumber) {
    if (interruptNumber == 0) {
        instanciaEncoder1 = this;
    } else if (interruptNumber == 1) {
        instanciaEncoder2 = this;
    }
}

void Encoder::PinOut(int pinEntrada, int encoder) {
    pin = pinEntrada;
    pinMode(pin, INPUT_PULLUP);
    if (encoder == 0) {
        attachInterrupt(digitalPinToInterrupt(pin), ISR_Encoder1, FALLING);
    } else if (encoder == 1) {
        attachInterrupt(digitalPinToInterrupt(pin), ISR_Encoder2, FALLING);
    }
}

void Encoder::handleInterrupt() {
    // Serial.printf("Interrompido %d interrupcoes", interrupcoes);
    interrupcoes++;
}

float Encoder::calcularRPM() {
    unsigned long tempoAtual = millis();
    float tempoDecorrido = (tempoAtual - lastTime) / 1000.0;
    if (tempoDecorrido > 0) {
        rpm = (interrupcoes / (float)furosPorRevolucao) / tempoDecorrido * 60.0;  
        interrupcoes = 0;
        lastTime = tempoAtual;
    }
    return rpm;
}

float Encoder::calcularDistancia() {
    float distancia = 0.0;
    float distanciaPorRevolucao = 21.36; // 3.14159 * 6.8;
    float giros = interrupcoes / 20.0; //furosPorRevolucao = 20;
    distancia = giros * distanciaPorRevolucao / 2.0;
    return distancia;
}

void Encoder::deletaDistancia(){
    interrupcoes = 0;
}

void Encoder::ISR_Encoder1() {
    if (instanciaEncoder1) instanciaEncoder1->handleInterrupt();
}

void Encoder::ISR_Encoder2() {
    if (instanciaEncoder2) instanciaEncoder2->handleInterrupt();
}

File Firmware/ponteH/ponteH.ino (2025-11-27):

// Classe para controle de um motor DC
class DCMotor {
  int pin1, pin2; // Definindo os pinos para controle do motor
  
  public:  
    // Método para inicializar os pinos que controlam o motor
    void Pinout(int in1, int in2) {
      pin1 = in1;
      pin2 = in2;
      pinMode(pin1, OUTPUT);  // Definindo o pino como saída
      pinMode(pin2, OUTPUT);  // Definindo o pino como saída
      digitalWrite(pin1, LOW);  // Iniciando os pinos em LOW
      digitalWrite(pin2, LOW);  // Iniciando os pinos em LOW
    }

    // Método para fazer o motor girar para frente
    void Forward() {
      digitalWrite(pin1, HIGH);  // Gira para frente, pino1 em HIGH e pino2 em LOW
      digitalWrite(pin2, LOW);
    }

    // Método para fazer o motor girar para trás
    void Backward() {
      digitalWrite(pin1, LOW);  // Gira para trás, pino1 em LOW e pino2 em HIGH
      digitalWrite(pin2, HIGH);
    }

    // Método para parar o motor
    void Stop() {
      digitalWrite(pin1, LOW);  // Parando os dois pinos
      digitalWrite(pin2, LOW);
    }
};

// class HCSR04{
//   int echo, trig;
//   float TempEcho = 0;

//   public:

//     void PinOut(int in1, int in2){
//       echo = in2;
//       trig = in1;
//       pinMode(trig, OUTPUT);
//       digitalWrite(trig, LOW);
//       pinMode(echo, INPUT);
//     }

//     void DisparaPulsoUltrassonico(){
//       digitalWrite(trig, HIGH);
//       delayMicroseconds(10);
//       digitalWrite(trig, LOW);
//     }


//     // Função para calcular a distancia em metros
//     float CalculaDistancia(float tempo_us){
//       return((tempo_us*VelocidadeSom_mporus)/2);
//     }

  
// };

// Classe para controle de um AGV (veículo autônomo)
class AGV {
  DCMotor Motor1, Motor2;  // Objetos de dois motores DC

  public:
    // Método para inicializar os motores com os pinos passados
    void Create(int in1, int in2, int in3, int in4) {
      Motor1.Pinout(in1, in2);  // Inicializa o primeiro motor
      Motor2.Pinout(in3, in4);  // Inicializa o segundo motor
    }

    // Método para o AGV ir para frente
    void ForwardAGV() {
      Motor1.Forward();
      Motor2.Forward();
    }

    // Método para o AGV ir para trás
    void BackwardAGV() {
      Motor1.Backward();
      Motor2.Backward();
    }


    // Método para o AGV virar para a esquerda
    void LeftAGV() {
      Motor1.Backward();
      Motor2.Forward();
    }

    // Método para o AGV virar para a direita
    void RightAGV() {
      Motor1.Forward();
      Motor2.Backward();
    }

    // Método para parar o AGV
    void StopAGV() {
      Motor1.Stop();
      Motor2.Stop();
    }
};

// Instância dos motores e do AGV
DCMotor Motor1, Motor2;
// AGV AGV1;
// HCSR04 Sensor1;

void setup() {
  Motor1.Pinout(12, 13);
  Motor2.Pinout(14, 27);
  // AGV1.Create(12, 13, 14, 27);  // Inicializando o AGV com os pinos dos motores
  Serial.begin(9600);  // Inicializando a comunicação serial para entrada de dados
  // Sensor1.PinOut(2, 3);
}

void loop() {
  Motor1.Forward();
  Motor2.Forward();
  delay(2000);
  Motor2.Stop();
  delay(500);
  Motor2.Backward();
  delay(2000);

  // AGV1.ForwardAGV();
  // delay(10000);
  // AGV1.StopAGV();
  // delay(2000);
  // AGV1.LeftAGV();
  // delay(10000);
  // AGV1.BackwardAGV();
  // delay(10000);
  // AGV1.RightAGV();
  // delay(10000);
  // AGV1.StopAGV();
  // delay(30000);
}

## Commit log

2025-10-06 (software) docs review: revisa der
2025-10-06 (Software) docs: artefato de elicitação de req não funcionais
2025-10-08 Added Prototype
    I've added the prototype of the cart controll screen.
2025-10-09 (software) docs: add doc dos casos de teste
2025-10-10 Update README.md
    Adição do esquemático do circuito
2025-10-23 feat: add firmware que percorre instrucoes
2025-11-18 chore: remove arquivos de software
2025-11-19 feat: integração de arquivos
2025-11-20 feat: add battery monitoring class with voltage and current readings
2025-11-21 refactor: improve battery monitoring class structure and documentation
2025-11-21 feat: implement battery monitoring system using INA219 sensor
2025-11-27 decidi que as funcoes que usam o encoder nao ficarao dentro do Atuadores.h ou Atuadores.cpp. Este codigo funciona, mas por algum motivo, ele nao consegue parar os motores quando chega aos 50 cm
2025-11-29 resolvido problema na motorizacao (motores nao paravam)
    [Atuadores.cpp, Encoder.cpp, main.ino]
